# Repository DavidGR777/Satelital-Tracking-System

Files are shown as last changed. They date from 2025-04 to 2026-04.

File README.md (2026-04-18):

# Satelital-Tracking-System
Mecatronic system focused on the tracking of satelital network NOAA. 

This project presents the design and implementation of a low-cost, portable satellite tracking and signal processing system capable of receiving and generating images from NOAA satellites.

The main objective is to develop a system that improves the quality and frequency of satellite image acquisition by combining real-time tracking with signal conditioning and processing. The proposed solution addresses key limitations of traditional static reception systems, such as low signal quality and inefficiencies in manual tracking.

The system integrates multiple engineering domains, including:

- **Mechanical design**: Development of a portable structure and a tracking mechanism with at least two degrees of freedom (DoF) to orient a directional antenna toward the satellite.

- **Electronic design**: Implementation of signal acquisition using an RTL-SDR device, motor control hardware, and feedback sensors for closed-loop operation.

- **Software development**: Processing of orbital data, coordinate transformations, real-time control algorithms, and signal demodulation to generate satellite images.

The solution is specifically designed to operate within the NOAA satellite frequency range (137–138 MHz) and to function under real environmental conditions, ensuring robustness and portability.

This system has potential applications in environmental monitoring, disaster management, agriculture, telecommunications, and scientific research, providing accessible satellite data for governments, companies, and researchers.

<p align="center">
  
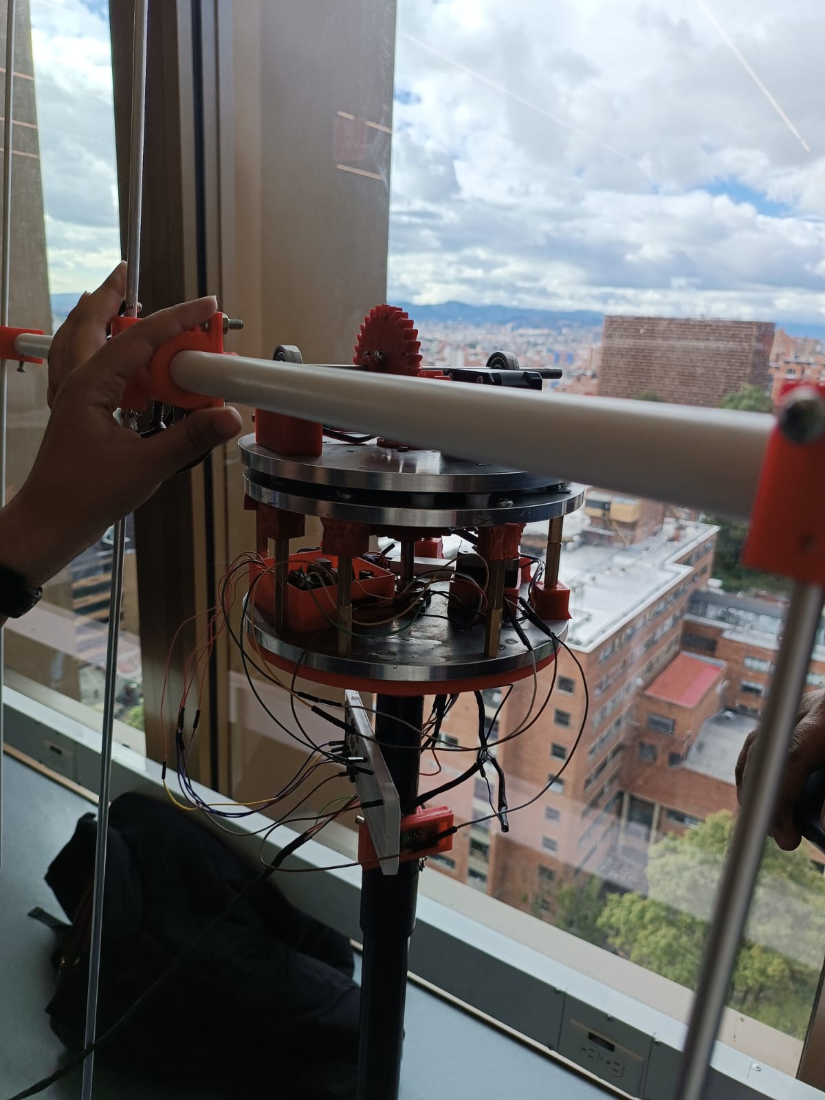
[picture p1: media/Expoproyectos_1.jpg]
  
</p>

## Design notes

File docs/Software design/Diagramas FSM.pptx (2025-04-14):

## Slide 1

RECEPTION_FSM

NULL/
/* recibe como parámetros:
bool Eusart_Rx_is_ready(), bool Eusar_READ() */
bool flag_inicio;
Static uint8_t* Rx_data = Rx_inicial;
uint16_t Azi, Azm, Azf;
uint8_t El, hi, hm, hf, mi, mm, mf;

No. | ESTADOS
0 | WAITING_SIGNAL
1 | RECEIVING_ALL_DATA
2 | ALL_PARAMETERS_SAVED

Eusart_Rx_is_ready() == 0
(Pregunta si hay otro dato para recibir)

1

Eusart_Rx_is_ready() == 1 /
*Rx_data = Eusar_READ();

0

flag_inicio == 1

*Rx_data != ‘$’ /
Rx_data++

flag_inicio == 0
(Pregunta si es momento de esperar recepción de datos)

2

*Rx_data == ‘$’/
(Deberán llegar 33 caracteres en ASCII decimal)
Azi = *(Rx_data-32)*100 *(Rx_data-31)*10 + *(Rx_data-30)
Azm = *(Rx_data-28)*100 *(Rx_data-27)*10 + *(Rx_data-26)
Azf = *(Rx_data-24)*100 *(Rx_data-23)*10 + *(Rx_data-22)
El = *(Rx_data-20)*10 + *(Rx_data-19)
hi = *(Rx_data-17)*10 + *(Rx_data-16)
mi = *(Rx_data-14)*10 + *(Rx_data-13)
hm = *(Rx_data-11)*10 + *(Rx_data-10)
mm = *(Rx_data-8)*10 + *(Rx_data-7)
hf = *(Rx_data-5)*10 + *(Rx_data-4)
mf = *(Rx_data-2)*10 + *(Rx_data-1)
flag_orientación = 1;
flag_inicio = 0;

Facultad de ingeniería – Pontificia Universidad Javeriana – Bogotá D.C

Eusart_Rx_is_ready()/Eusart_READ():
Estas funciones indican si el puerto de UART para recepción tiene un dato disponible para recibir. Además, permite guardarlo en una variable interna.

Breve descripción de la FSM:
Esta FSM hace lectura del pin Rx al que llegan los comando por el puerto serial, y sigue el estado del puerto por si ha llegado información. Una vez guardado el dato completo se mira qué tipo de comando fue ingresado y se modifica en dado caso el modo de operación del control, o la velocidad de referencia.

Fecha: 4 de mayo 2024

Autores: Valeria Jimenez, Jerónimo Rueda & David Esteban González

FSM: PWM_READER_FSM

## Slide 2

TRANSMISSION_FSM

flag_timer_Tx == 1 /
flag_timer_Tx = 0
step2dig(Az);
Tx_data = msj[0];

No. | ESTADOS
0 | WAITING_TIMER
1 | SENDING_AZ
2 | SENDING_EL

NULL/
/* recibe como parámetros:
bool flag_timer_Tx */
Static uint8_t* Tx_data;
Static uint8_t state = 0;
Static uint16_t Az;
Static uint8_t El;

Flag_Tx == 1 /
Tx_string();
(El ángulo se transmitirá en 3 dígitos. Ejm: Az: 15.3)

0

1

flag_timer_Tx == 0
(Pregunta si ya es momento de volver a enviar los ángulos al usuario)

Flag_Tx == 0

2

Flag_Tx == 0/
Flag_Tx == 1;
step2dig(El);
Tx_data = msj[0];

Flag_Tx == 1 /
Tx_string();
(El ángulo se transmitirá en 3 dígitos. Ejm: El: 15.3)

step2dig():
Esta función transforma los ángulos a transmitir en un arreglo de dígitos del mismo ángulo. De modo que en Tx se transmita posición por posición del arreglo
El arreglo a transmitir es de tipo char

Facultad de ingeniería – Pontificia Universidad Javeriana – Bogotá D.C

Tx():
Esta función controla el flujo de transmisión de cada digito de los ángulos hacia el puerto serial.Utiliza las funciones
Eusart_Tx_is_ready()/Eusart_WRITE():

Breve descripción de la FSM:
Esta FSM escribe en el pin Tx la posición angular Az y El de los motores. Espera que se produzaca la interrupción del timer, pregunta si se puede escribir en el puerto y una vez se completa el envío de Az, pasa a enviar El. Al finalizar, se queda esperando hasta que flag_timer_Tx sea nuevamente 1

Fecha: 4 de mayo 2024

Autores: Valeria Jimenez, Jerónimo Rueda & David Esteban González

FSM: TRANSMISSION_FSM

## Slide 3

INITIAL_POSITION_FSM

NULL/
/* recibe como parámetros:
bool flag_inicio, dir;
Static uint16_t Azi;
Static uint32_t N, steps;
if( Azi <= 180 ){
dir = 1;
}else{
dir = 0;
Azi -= 180;
}
num_steps(Azi); //determinar # pasos a dar

No. | ESTADOS
0 | WAITING_SIGNAL
1 | MOVING_ TO_AZi

flag_orientacion == 1/
control();
(se configura a la velocidad estándar de inicialización y dirección dir)

0

1

N <= steps/
(Pregunta si aún no se ha alcanzado el # de pasos esperado)

flag_orientacion == 0
(Pregunta si es hora de iniciar la orientación inicial)

N > steps /
N = 0;
flag_orientacion = 0;

Control():
Esta función establece y configuralas salidas de microcontrolador para el motor Az, para ir a la posición inicial Azi, según los parámetros recibidos.

num2steps():
Esta función calcula cuantos pasos se deben realizar para que el motor alcance el ángulo deseado

Breve descripción de la FSM:
Esta FSM describe el proceso de orientación inicial del sistema. Desde la orientación manual (Az = 0°) hasta el primer punto de trayectoria Azi

Fecha : 4 de mayo 2024

Facultad de ingeniería – Pontificia Universidad Javeriana – Bogotá D.C

Autores: Valeria Jimenez, Jerónimo Rueda & David Esteban González

FSM: INITIAL_POSITION_FSM

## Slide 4

OPERATION_FSM

NULL/
/* recibe como parámetros:
bool INICIO_GetValue();
bool operation_flag, flag_inicio;

No. | ESTADOS
0 | WAITING_BUTTON
1 | OPERATING_PHASE

INICIO_GetValue() == 1 && flag_inicio == 0/
control();
operation_flag = 1;

0

1

operation_flag == 1/
operation();
(Mantiene los motores en movimiento a velocidad cte según los parámetros ingresados. Cuando acaba la operación, operation_flag cambia a 0)

INICIO_GetValue() == 0 || flag_inicio == 1
(Pregunta si el botón de inicio fue activado y además si la recepción de datos ya fue ejecutada)

operation_flag == 0/
flag_inicio == 1;

Control():
Esta función establece y configura las salidas de microcontrolador para ambos motores, para ir a la velocidad calculada a través de los puntos de trayectoria del satélite

Breve descripción de la FSM:
Esta FSM describe la operación del sistema de modo que espera la señal de inicio (pulsador físico) y finaliza una vez se da la condición internamente en operation().

Fecha : 4 de mayo 2024

Facultad de ingeniería – Pontificia Universidad Javeriana – Bogotá D.C

Autores: Valeria Jimenez, Jerónimo Rueda & David Esteban González

FSM: OPERATION_FSM

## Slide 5

flag_inicio == 0/
(Espera a que la recepción de los parámetros finalice)
parametros();
flag_orientación = 1;
if( Azi <= 180 ) dir = 1;
else{
dir = 0;
Azi -= 180;
}
num_steps(Azi);

No. | ESTADOS
0 | WAITING_RECEPTION
1 | INITIAL_POSITION_PHASE
2 | WAITING_TRACKING_SIGNAL
3 | ENDING_INITIAL_POSITION
4 | TRACKING_PHASE

N <= steps/
(Pregunta si aún no se ha alcanzado
el # de pasos esperado)

MAIN_FSM

NULL/
/* recibe como parámetros:
uint_8_t state;

flag_orientacion == 1/
control()

0

1

INICIO_GetValue() == 0

operation_flag == 0/
flag_inicio == 1;

flag_orientacion == 0/

3

flag_inicio == 1/
recepción_fsm();

2

N > steps /
N = 0;
flag_orientacion = 0;

INICIO_GetValue() == 1/
control();
operation_flag = 1;

4

Breve descripción de la FSM:
Esta FSM describe el funcionamiento general del sistema de seguimiento. Partiendo desde la recepción, la ubicación inicial del sistema, y la operación de seguimiento. Una vez finaliza, espera por nuevas instrucciones de recepción

Fecha: : 4 de mayo 2024

operation_flag == 1/
operation();

Facultad de ingeniería – Pontificia Universidad Javeriana – Bogotá D.C

Autores: Valeria Jimenez, Jerónimo Rueda & David Esteban González

FSM: MAIN_FSM

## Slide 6

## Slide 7

Por puerto serial, el DC_ref se modifica directamente con el comando Wxxxxx. Queda guardado como valor entre 000.00 y 100.00% para el duti cycle

Aux = Lectura de ADC
DC_ref = Aux/4095*100 (Valor entre 0 y 100% para el duti cycle)

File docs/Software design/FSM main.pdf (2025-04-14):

No. | ESTADOS
0 | WAITING_RECEPTION

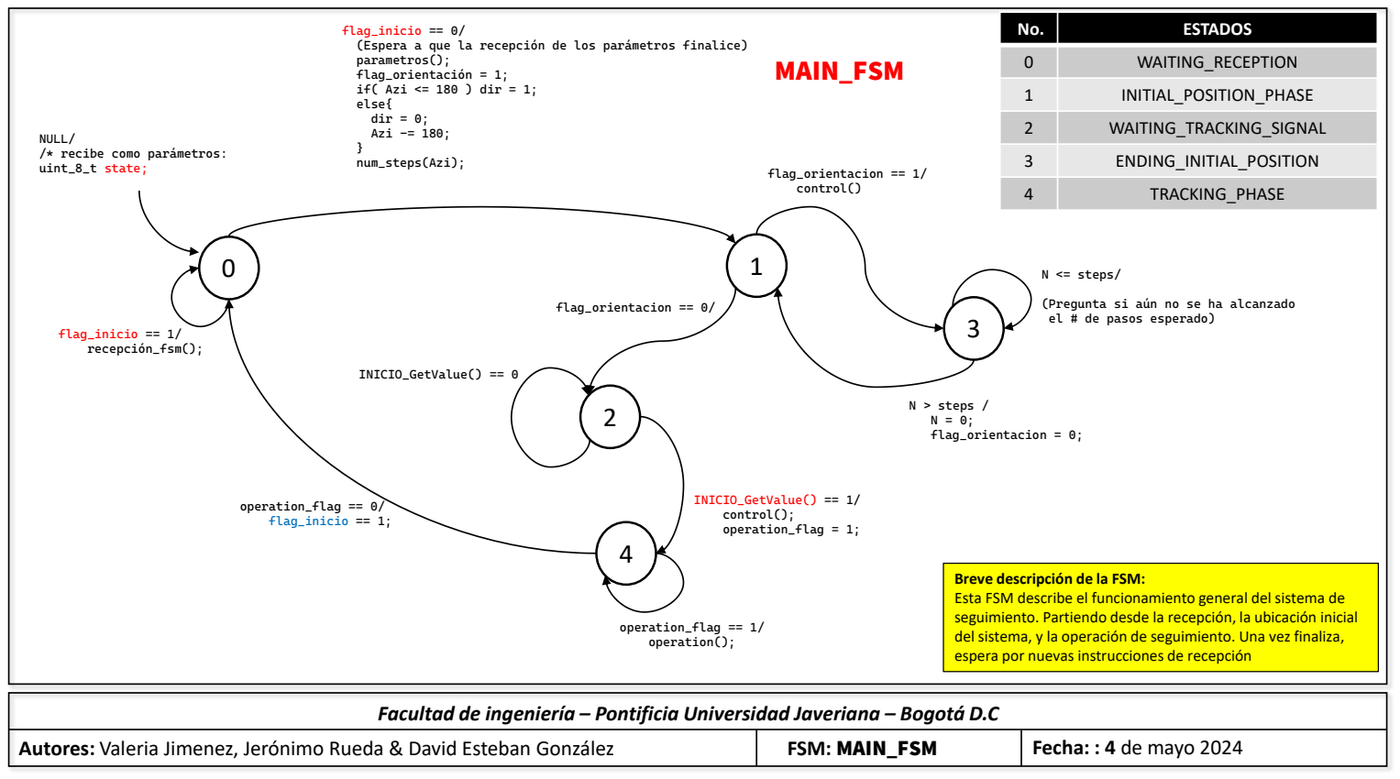
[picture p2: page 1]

1 | INITIAL_POSITION_PHASE
2 | WAITING_TRACKING_SIGNAL
3 | ENDING_INITIAL_POSITION
4 | TRACKING_PHASE

Breve descripción de la FSM:
Esta FSM describe el funcionamiento general del sistema de seguimiento. Partiendo desde la recepción, la ubicación inicial del sistema, y la operación de seguimiento. Una vez finaliza, espera por nuevas instrucciones de recepción
Autores: Valeria Jimenez, Jerónimo Rueda & David Esteban González | FSM: MAIN_FSM

## Facultad de ingeniería – Pontificia Universidad Javeriana – Bogotá D.C Fecha: : 4 de mayo 2024

# MAIN_FSM

0 | 1

flag_inicio == 0/
(Espera a que la recepción de los parámetros finalice) parametros();
flag_orientación = 1;
if( Azi <= 180 ) dir = 1;
else{
dir = 0;
Azi -= 180;
}
num_steps(Azi);

NULL/
/* recibe como parámetros: uint_8_t state;

2

4

flag_inicio == 1/ | 3
recepción_fsm();

flag_orientacion == 1/
control()

flag_orientacion == 0/

N <= steps/

(Pregunta si aún no se ha alcanzado el # de pasos esperado)

N > steps /
N = 0;
flag_orientacion = 0;

INICIO_GetValue() == 1/
control();
operation_flag = 1;

INICIO_GetValue() == 0

operation_flag == 1/
operation();

operation_flag == 0/
flag_inicio == 1;

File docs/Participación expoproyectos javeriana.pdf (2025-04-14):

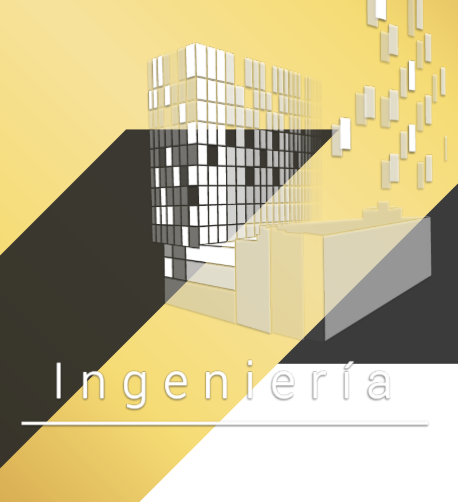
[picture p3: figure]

# Certificado de Participación

EN RECONOCIMIENTO AL PROYECTO Sistema de seguimiento satelital

Valeria Jiménez Moyano, David González Rozo, Jerónimo Rueda Giraldo

POR SU COMPROMISO Y PARTICIPACIÓN EXPO PROYECTOS 2410
PONTIFICIA UNIVERSIDAD JAVERIANA

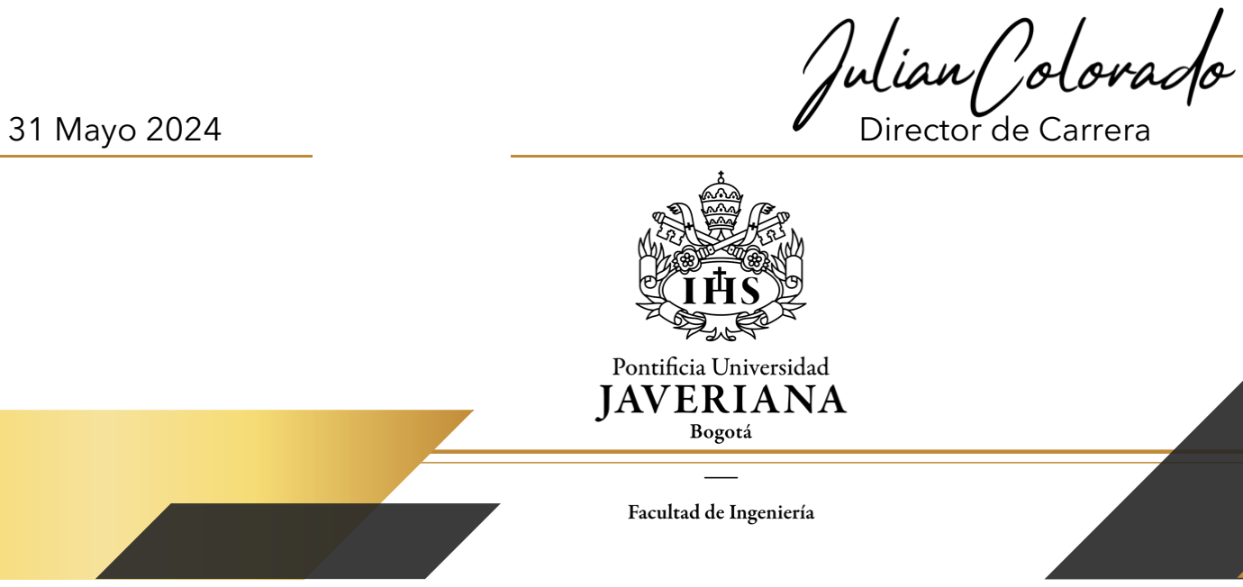
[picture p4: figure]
31 Mayo 2024; Director de Carrera

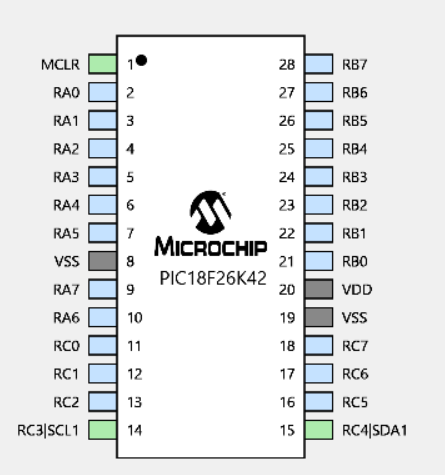
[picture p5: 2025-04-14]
docs/Electronic design/PIC18F26K42.png

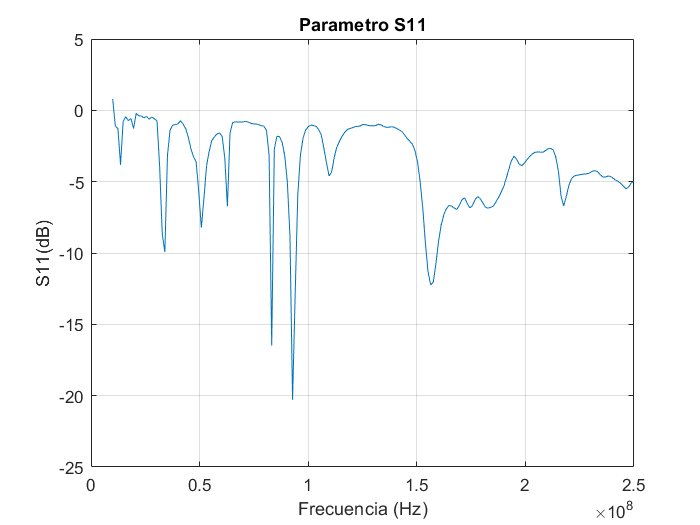
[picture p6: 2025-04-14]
docs/Sintonizacion antena.png

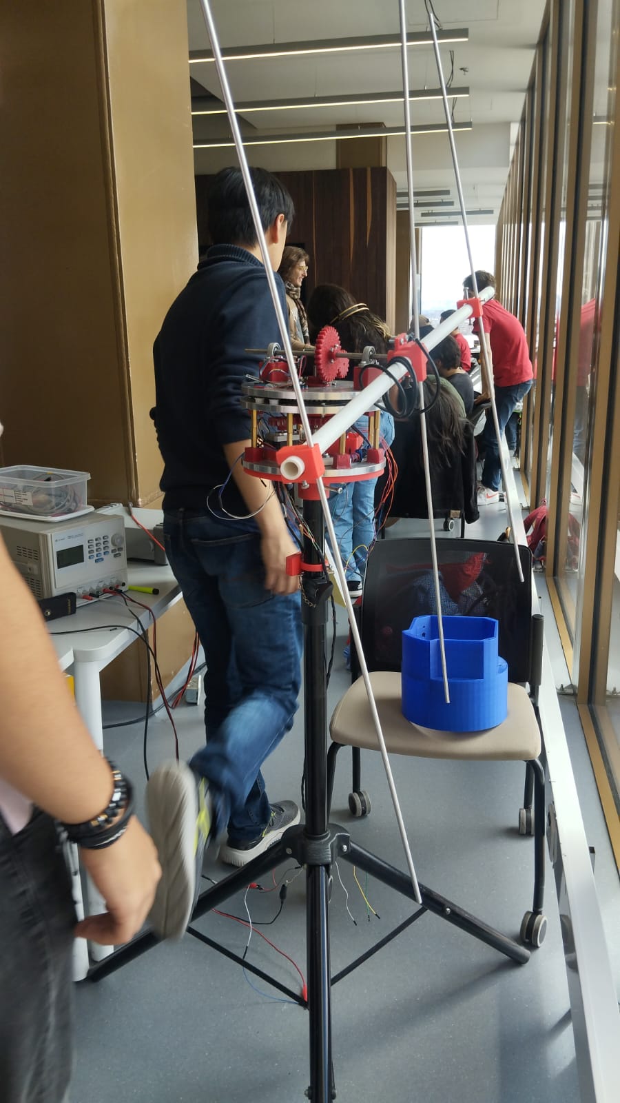
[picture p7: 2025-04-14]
media/Expoproyectos 2.jpg

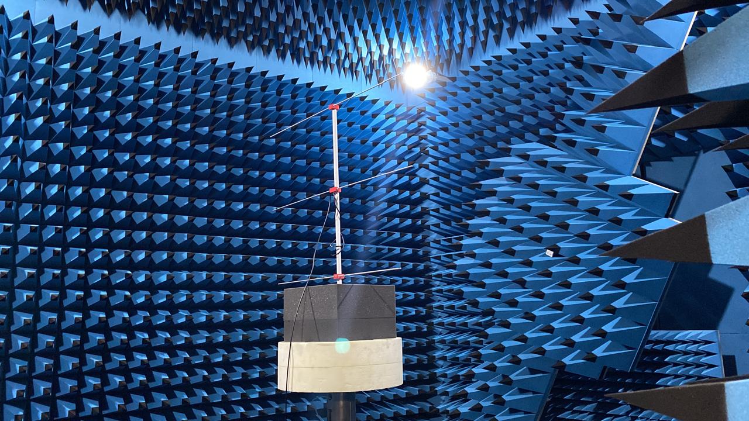
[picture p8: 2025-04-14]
media/Sintonización.jpeg

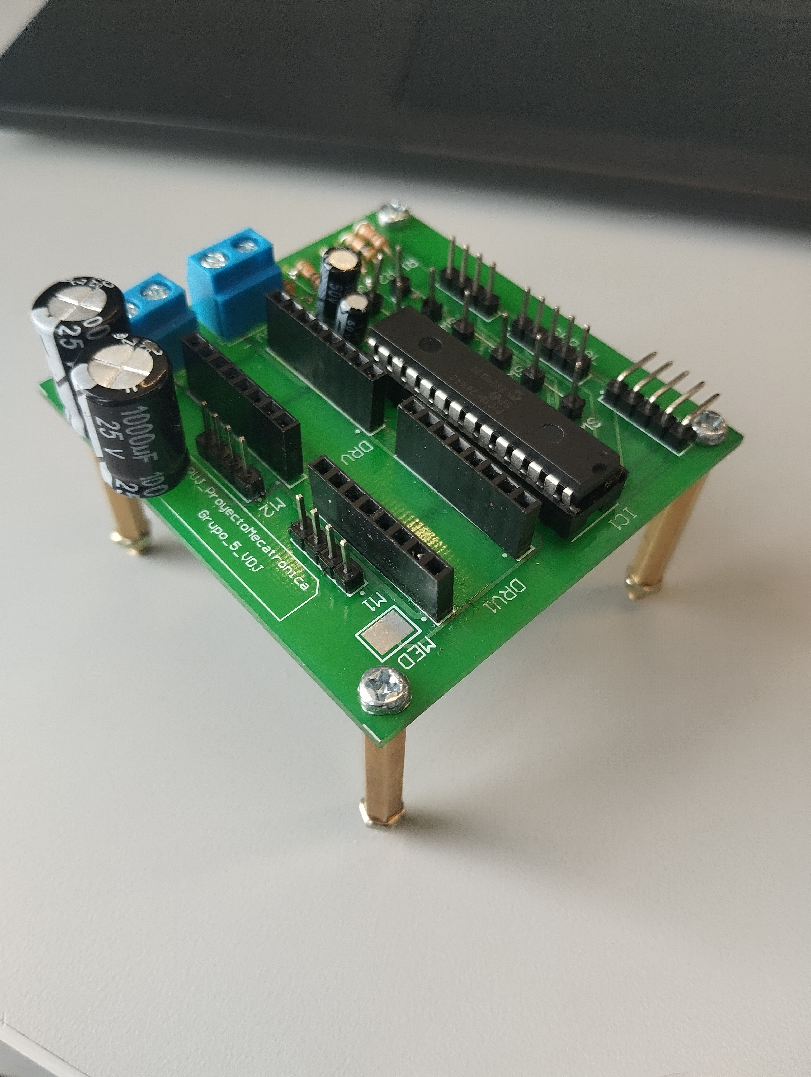
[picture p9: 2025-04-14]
media/PCB.jpg

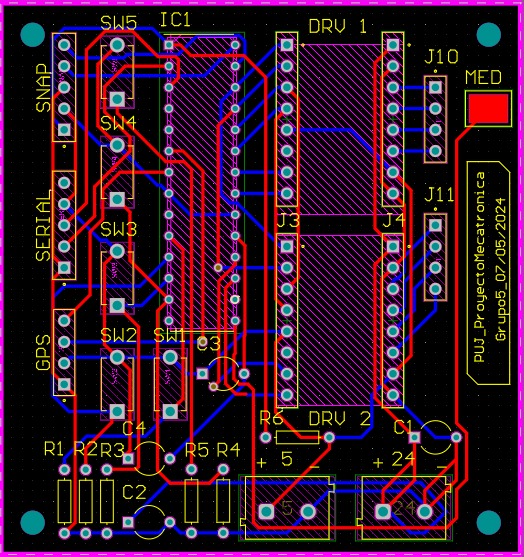
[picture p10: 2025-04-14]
src/PCB/PCB2D.jpeg

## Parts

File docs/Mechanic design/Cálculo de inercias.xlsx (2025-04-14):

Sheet: Hoja1
 | Parte superior PARA MOTOR INFERIOR
 | Antena | engranaje1 sup | engranaje2 sup | eje sup | motor superior | Soporte L | electrónica | brida motor | brida engranaje | brida antena | contrapeso | chumasera1 | escalon1 | chumasera2 | escalon2 | chumasera3 | escalon3
Material |  | No sé | No sé | aluminio |  | No sé |  | aluminio | aluminio | bronce | bronce |  | PETG |  | PETG |  | PETG | Masa total (downward para rodmientos )
masa (kg) | 1.28565 | 0.34172 | 0.08331 | 0.1 | 0.54871 | 0.03626 | 0.17 | 0.04355 | 0.06 | 0.15402 | 0.371 | 0.05013 | 0.05528 | 0.05013 | 0.05528 | 0.05013 | 0.05528 | 3.51045 |  |  | Parte superior PARA MOTOR SUPERIOR
rext (m) |  | 0.04 | 0.02125 |  |  |  |  |  |  |  | 0.02 |  |  |  |  |  |  |  |  |  |  | Antena | engranaje1 sup | engranaje2 sup | eje sup | brida motor | brida engranaje | brida antena | motor (datashet)
rint o L |  | 0.008 | 0.01 | 0.008 |  | rext1 |  | 0.0075 | 0.01 |  |  |  |  |  |  |  |  | MENOS: eje sup (para desplazamiento a eje del motor inferior) |  |  | Material |  | No sé | No sé | aluminio | aluminio | aluminio | aluminio |  | masa TOTAL | MAS: disco (para peso sobre rodamientos de transferencia
a |  |  |  |  | 0.0405 | rext2 |  | 0.02 | 0.025 | 0.018 |  | 0.02276 | 0.02276 | 0.02276 | 0.02276 | 0.02276 | 0.02276 |  |  |  | masa (kg) |  |  |  |  |  |  |  |  | 0
b |  |  |  |  | 0.042 | rint |  | 0.005 | 0.008 | 0.06221 |  | 0.05485 | 0.05485 | 0.05485 | 0.05485 | 0.05485 | 0.05485 |  |  |  | radio (mm) |  |  |  |  |  |  |  |  | MENOS: brida y eng1 (para desplazar todo al eje del motor
unidades | 1 | 1 | 1 | 1 | 1 | 1 | 1 | 1 | 1 | 1 | 1 | 1 | 1 | 1 | 1 | 1 | 1 |  |  |  | rext1
d (distancia al eje) m | 0.192 | 0.0245 | 0.05811 | 0.04693 | 0.05485 | 0.0533 | 0.0703 | 0.0549 | 0.014 | 0.169 | 0.084 | 0.0482 | 0.0482 | 0.06104 | 0.06104 | 0.0838 | 0.0838 |  |  |  | rext2
Inercia (kg m2) |  | 0.00014215552 | 1.148766797e-05 | 5.333333333e-07 | 0.0001556621681 | 2.410829e-05 | 0.0001203339 | 5.511796875e-06 | 1.2795e-05 | 5.383106942e-05 | 0.0255324055 | 1.473212127e-05 | 1.624559473e-05 | 1.473212127e-05 | 1.624559473e-05 | 1.473212127e-05 | 1.624559473e-05 |  |  |  | rint
Inercia despl. | 0.0473942016 | 0.00034727295 | 0.0002928065516 | 0.0002207758233 | 0.001806468549 | 0.0001271189614 | 0.0009604892 | 0.0001367719324 | 2.4555e-05 | 0.004452796289 | 0.0281501815 | 0.0001311961425 | 0.0001446743019 | 0.0002015105659 | 0.0002222123296 | 0.0003667670385 | 0.0004044460779 | Inercia TOTAL |  |  | d (distancia al eje) mm |  | 0 |  |  | 0 |  |  | 0
Inercia TOTAL | 0.0473942016 | 0.00034727295 | 0.0002928065516 | 0.0002207758233 | 0.001806468549 | 0.0001271189614 | 0.0009604892 | 0.0001367719324 | 2.4555e-05 | 0.004452796289 | 0.0281501815 | 0.0001311961425 | 0.0001446743019 | 0.0002015105659 | 0.0002222123296 | 0.0003667670385 | 0.0004044460779 | 0.08538424481 |  |  | Inercia (kg mm2) |  | 0 | 0 | 0 | 0 | 0 | 0 |  | Inercia TOTAL
 |  |  |  |  |  |  |  |  |  |  |  |  |  |  |  |  |  |  |  |  | Inercia despl. | 0 | 0 | 0 | 0 | 0 | 0 | 0 | 0 | 0
 |  |  |  |  |  |  |  |  |  | 5.941619142e-05
 |  |  |  |  |  |  |  |  |  |  |  |  |  |  |  |  |  |  |  |  |  |  |  | BRIDAS engranaje y antena TIENEN rint = 8 mm
 |  |  |  |  |  |  |  |  |  |  |  |  |  |  |  |  |  |  |  |  |  |  |  | BRIDA e motor TIENEN rint = …..............
 | Parte inferior PARA MOTOR INFERIOR
 |  | disco | eje inf | brida de giro | brida engranaje | brida motor | engranaje1 inf | engranaje2 inf | motor (datasheet)
 | Material | aluminio | aluminio | aluminio | aluminio | aluminio | No sé | No sé |  | Masa total (para carga axial rodamientos, es decir la vertical)
 | masa (kg) | 1.65 | 0.07402 | 0.05976 | 0 | 0.04355 |  |  |  | 1.82733
 | radio (m) |  | 0.004 |  | 0 |  |  |  |  | MENOS: brida motor y eng1 (tanto para el peso como para el desplazamos a eje del motor
 | rext1 | 0.03 |  | 0.01 | 0 |  |  |  |  | 1.82733 |  |  |  | Antena PARA MOTOR INFERIOR |  |  |  |  |  |  | Antena PARA MOTOR SUPERIOR
 | rext2 | 0.11 |  | 0.025 | 0 |  |  |  |  |  |  |  |  |  | Boom | dipolo | reflector | director | contrapeso |  |  | Boom | dipolo | reflector | director | contrapeso
 | rint | 0.008 |  | 0.008 | 0 | 0.005 |  |  |  |  |  |  |  | Material | PVC | Aluminio | Aluminio | Aluminio | bronce | masa TOTAL | Material | PVC | Aluminio | Aluminio | Aluminio | bronce | masa TOTAL
 | d (distancia al eje) mm | 0 | 0 | 0 | 0 | 0 | 0 |  | 0 |  |  |  |  | masa (kg) | 0.715 | 0.04677 | 0.09486 | 0.08636 | 0.296 | 1.23888 | masa (kg) | 0.715 | 0.04677 | 0.09486 | 0.08636 | 0.296 | 1.28565
 | Inercia (kg m2) | 0.0108306 | 4.7808e-07 | 2.548764e-05 | 0 | 1.08875e-06 | 0 | 0 | 8.2e-06 | Inercia TOTAL |  |  |  | Longitud (m) | 1.5 | 0.545 | 1.070 | 1.010 |  | MAS: 1 dipolo | Longitud (m) | 1.5 | 0.545 | 1.070 | 1.010 |  | MAS: 1 dipolo
 | Inercia despl. | 0.0108306 | 4.7808e-07 | 2.548764e-05 | 0 | 1.08875e-06 | 0 | 0 | 8.2e-06 | 0.01086585447 |  |  |  | rext (m) | 0.0167 |  |  | r | 0.04000 |  | rext (m) | 0.0167 |  |  | r | 0.04000
 |  |  |  |  |  |  |  |  |  |  |  |  |  | rint (m) | 0.0127 |  |  | h | 0.0458 |  | rint (m) | 0.0127 |  |  | h | 0.0458
 |  |  |  |  |  |  |  |  |  |  |  |  |  | d (distancia al eje) m | 0.31145 | 0.60809 | 0.23687 | 1.03382 | 0.5293 |  | d (distancia aleje) m | 0.246 | 0.558 | 0.12 | 0.996 | 0.504
 |  |  |  |  |  |  |  |  | mk |  |  |  |  | Inercia (kg m2) | 0.1341205451 | 0.00463061975 | 0.0090504345 | 0.007341319667 | 0.0001701417867 |  | Inercia (kg m2) | 0.1341205451 | 0.008550359667 | 0.0090504345 | 0.007341319667 | 0.0001701417867
 |  |  |  |  |  |  |  |  |  |  |  |  |  | Inercia despl. | 0.2034656632 | 0.02192492392 | 0.01437278217 | 0.09964148798 | 0.08309705483 | TOTAL | Inercia despl. | 0.1773828283 | 0.02311285395 | 0.0104164185 | 0.09301182143 | 0.07535887779 | Inercia TOTAL | Torque
 |  |  |  |  |  |  |  |  |  |  |  |  |  | Inercia TOTAL | 0.2034656632 | 0.04384984784 | 0.01437278217 | 0.09964148798 | 0.08309705483 | 0.444426836 | Inercia TOTAL | 0.1773828283 | 0.04622570789 | 0.0104164185 | 0.09301182143 | 0.07535887779 | 0.4023956539 | 0.06320816151
 |  |  |  |  |  |  |  |  |  | VELOCIDADES MÁXIMAS ( manual)
 |  |  |  |  |  |  |  |  |  | w_Az (rad/s) | 0.10472
 |  |  |  |  |  |  |  |  |  | w_El (rad/s) | 0.15708 |  |  |  |  |  |  |  |  |  |  |  |  |  |  |  | 0.03682087962
 |  |  |  |  |  |  |  |  |  |  | pi rad en 30 s
 |  |  |  |  |  |  |  |  |  |  |  |  |  |  |  |  |  |  |  |  |  |  | I contrapeso = (1/4)*m*r^2
 |  |  |  |  |  |  |  |  |  |  |  |  |  | Antena PARA MOTOR INFERIOR
 |  |  |  |  |  |  |  |  |  |  |  |  |  |  | Boom | dipolo | reflector | director | contrapeso
 |  |  |  |  |  |  |  |  |  |  |  |  |  | Material | PVC | Aluminio | Aluminio | Aluminio | bronce
 |  |  |  |  |  |  |  |  |  |  |  |  |  | masa (kg) | 0.715 | 0.04677 | 0.09486 | 0.08636 | 0.296
 |  |  |  |  |  |  |  |  |  |  |  |  |  | Longitud (mm) | 1.5 | 0.545 | 1.070 | 1.010
 |  |  |  |  |  |  |  |  |  |  |  |  |  | rext (mm) | 0.0167 |  |  | a
 |  |  |  |  |  |  |  |  |  |  |  |  |  | rint (mm) | 0.0127 |  |  | b
 |  |  |  |  |  |  |  |  |  |  |  |  |  | d (distancia al eje) mm
 |  |  |  |  |  |  |  |  |  |  |  |  |  | Inercia (kg mm2) | 0.0001573401401 | 0.00463061975 | 0.0090504345 | 0.007341319667 | 0
 |  |  |  |  |  |  |  |  |  |  |  |  |  | Inercia despl. | 0.0001573401401 | 0.00463061975 | 0.0090504345 | 0.007341319667 | 0
 |  |  |  |  |  |  |  |  |  |  |  |  |  | Inercia TOTAL | 0.0001573401401 | 0.0092612395 | 0.0090504345 | 0.007341319667 | 0

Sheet: Hoja2
 |  |  |  |  |  |  |  |  |  |  |  | TABLA DE INERCIAS MOTOR ELEVATION
TABLA DE INERCIAS MOTOR AZIMUTH
 |  |  |  |  |  |  |  |  |  |  |  |  | Material | masa (kg) | Longitud (m) | rint (m) | rext1 (m) | rext2 (m) | Inercia (kg m2) | d (distancia al eje) m | Inercia despl.
 | Material | masa (kg) | Longitud (m) | rint (m) | rext1 (m) | rext2 (m) | a (m) | b (m) | Inercia (kg m2) | d (distancia al eje) m | Inercia despl. | Antena
Antena |  |  |  |  |  |  |  |  |  |  |  | Boom | PVC | 0.7149 | 1.5000 | 0.0127 | 0.0167 |  | 0.1341 | 0.2460 | 0.1774
Boom | PVC | 0.7149 | 1.5000 | 0.0127 | 0.0167 |  |  |  | 0.1341 | 0.3115 | 0.2035 | dipolos | aluminio | 0.1072 | 0.5450 |  |  |  | 0.0027 | 0.6364 | 0.0461
dipolos | aluminio | 0.1072 |  |  | 0.0063 |  |  |  | 2.161286e-06 | 0.6081 | 0.0219 | reflector | aluminio | 0.1020 | 1.0700 |  |  |  | 0.0097 | 0.1300 | 0.0115
reflector | aluminio | 0.1020 |  |  | 0.0063 |  |  |  | 0.0091 | 0.2369 | 0.0144 | director | aluminio | 0.0955 | 1.0100 |  |  |  | 0.0081 | 1.0073 | 0.1050
director | aluminio | 0.0955 |  |  | 0.0063 |  |  |  | 0.0073 | 1.0338 | 0.0996 | contrapeso | bronce | 0.3080 | 0.0458 |  | 0.0400 |  | 0.0002 | 0.5040 | 0.0784
contrapeso | bronce | 0.3080 | 0.0458 |  | 0.0400 |  |  |  | 0.0002 | 0.5293 | 0.0831 | soporte dipolo | PE alto impacto | 0.02447 |  |  |  |  | 8.07545e-06 | 0.568 | 0.0079
soporte dipolo | PE alto impacto | 0.02447 |  |  |  |  |  |  | 6.54169e-06 | 0.568 | 0.0079 | soporte reflector | PE alto impacto | 0.01929 |  |  |  |  | 4.70458e-06 | 0.13 | 0.0003
soporte reflector | PE alto impacto | 0.01929 |  |  |  |  |  |  | 5.94917e-06 | 0.13 | 0.0003 | soporte director | PE alto impacto | 0.01929 |  |  |  |  | 4.70458e-06 | 1.0073 | 0.0196
soporte director | PE alto impacto | 0.01929 |  |  |  |  |  |  | 5.94917e-06 | 1.0073 | 0.0196 | TOTAL |  | 1.39064 |  |  |  |  |  |  | 0.44615
TOTAL |  | 1.39064 |  |  |  |  |  |  |  |  | 0.45031
 |  |  |  |  |  |  |  |  |  |  |  | Parte superior
Parte superior |  |  |  |  |  |  |  |  |  |  |  | eje sup | acero | 0.1000 |  |  | 0.0080 |  | 3.2e-06 | 0.0000 | 3.2e-06
engranaje1 El | acero AISI 1020 | 0.3417 | 0.0100 | 0.0080 | 0.0400 |  |  |  | 0.0001 | 0.0245 | 0.0004 | brida antena | bronce | 0.1540 |  |  |  |  | 0.00006 | 0.0000 | 0.0001
engranaje2 El | acero AISI 1020 | 0.0833 | 0.0100 | 0.0100 | 0.0213 |  |  |  | 1.218191797e-05 | 0.0581 | 0.0003 | acople antena | PETG | 0.02264 |  |  |  |  | 0.00002 | 0.0000 | 2.311239e-05
eje horizontal | acero | 0.1000 | 0.0080 |  |  |  |  |  | 5.333333333e-07 | 0.0469 | 0.0002 | Inercia motor | . |  |  |  |  |  | 8.2e-06 | 0.0000 | 8.2e-06
motor superior | . | 0.5487 |  |  |  |  |  |  | 0.0005 | 0.0549 | 0.0021 | TOTAL |  | 0.2767 |  |  |  |  |  |  | 0.0001
Soporte L | acero | 0.0363 |  |  |  |  |  |  | 0.00006 | 0.0533 | 0.0002
electrónica | PE alto impacto | 0.1700 |  |  |  |  |  |  | 0.00006 | 0.0703 | 0.0009 | Transmisión
brida motor | bronce | 0.0435 | 0.0200 | 0.0050 | 0.0075 | 0.0200 |  |  | 6.963463542e-06 | 0.0549 | 0.0001 | brida motor | bronce | 0.0347 |  | 0.0050 | 0.0075 | 0.0200 | 8.7935625e-06 | 0.0000 | 8.7935625e-06
brida engranaje | bronce | 0.0600 | 0.0200 | 0.0080 | 0.0100 | 0.0250 |  |  | 1.4795e-05 | 0.0140 | 2.6555e-05 | brida engranaje | bronce | 0.0598 |  | 0.0080 | 0.0100 | 0.0250 | 2.548764e-05 | 0.0000 | 2.548764e-05
brida antena | bronce | 0.1540 |  |  |  |  |  |  | 0.00199 | 0.1690 | 0.0064 | engranaje1 sup | acero AISI 1020 | 0.0833 |  |  |  |  | 6.7689375e-05 | 0.0000 | 0.0001
acople antena | PETG | 0.02264 |  |  |  |  |  |  | 6.53528e-06 | 0.1700 | 0.0007 | engranaje2 sup | acero AISI 1020 | 0.3417 |  |  |  |  | 0.0002 | 0.0000 | 0.0002
contrapeso | bronce | 0.3710 |  |  | 0.0200 |  |  |  | 0.0255 | 0.0840 | 0.0282 | TOTAL |  | 0.5195 |  |  |  |  |  |  | 0.0003
chumasera1 | . | 0.0501 |  |  |  |  |  |  | 0.0008 | 0.0482 | 0.0009
escalon1 | PETG | 0.0553 |  |  |  |  | 0.0228 | 0.0549 | 1.624559473e-05 | 0.0482 | 0.0001 | TOTALES | MASA | 2.18683 |  |  |  |  |  | INERCIA | 0.44659
chumasera2 | . | 0.0501 |  |  |  |  |  |  | 0.0008 | 0.0610 | 0.0010
escalon2 | PETG | 0.0553 |  |  |  |  | 0.0228 | 0.0549 | 1.624559473e-05 | 0.0610 | 0.0002
chumasera3 | . | 0.0501 |  |  |  |  |  |  | 0.0008 | 0.0838 | 0.0012
escalon3 | PETG | 0.0553 |  |  |  |  | 0.0228 | 0.0549 | 1.624559473e-05 | 0.0838 | 0.0004
base giratoria | aluminio | 1.65 | 0.03 | 0.0080 | 0.0600 | 0.1100 |  |  | 0.0067 | 0.0000 | 0.0067
eje vertical | acero | 0.07402 |  |  | 0.0040 |  |  |  | 5.9216e-07 | 0.0000 | 5.9216e-07
Inercia motor | . |  |  |  |  |  |  |  | 8.2e-06 |  | 8.2e-06
Cubierta | PE alto impacto | 0.8556 |  |  |  |  |  |  | 0.0108 | 0.0000 | 0.0108
Tapa de cubierta | PE alto impacto | 0.17662 |  |  |  |  |  |  | 0.0011 | 0.0000 | 0.0011 |  |  |  | 0.00004
TOTAL |  | 5.00368 |  |  |  |  |  |  |  |  | 0.06175 |  |  |  | 0.00002
 |  |  |  |  |  |  |  |  |  |  |  |  |  |  | 0.00006
Transmisión
brida engranaje | bronce | 0.05976 |  | 0.0100 | 0.0250 | 0.0080 |  |  | 2.548764e-05 | 0.0000 | 2.548764e-05
brida motor | bronce | 0.04355 |  | 0.0050 | 0.0075 | 0.0200 |  |  | 1.08875e-06 |  | 1.08875e-06
engranaje1 Az | acero AISI 1020 |  |  |  |  |  |  |  | 0.0000 |  | 0.0000
engranaje2 Az | acero AISI 1020 |  |  |  |  |  |  |  | 0.0000 | 0.0000 | 0.0000
TOTAL |  | 0.10331 |  |  |  |  |  |  |  |  | 0.00003
TOTALES | MASA | 5.37717 |  |  |  |  |  |  |  | INERCIA | 0.49917
 |  |  |  | 730.13
 |  |  |  | 7315.35
 |  |  |  | 8045.48

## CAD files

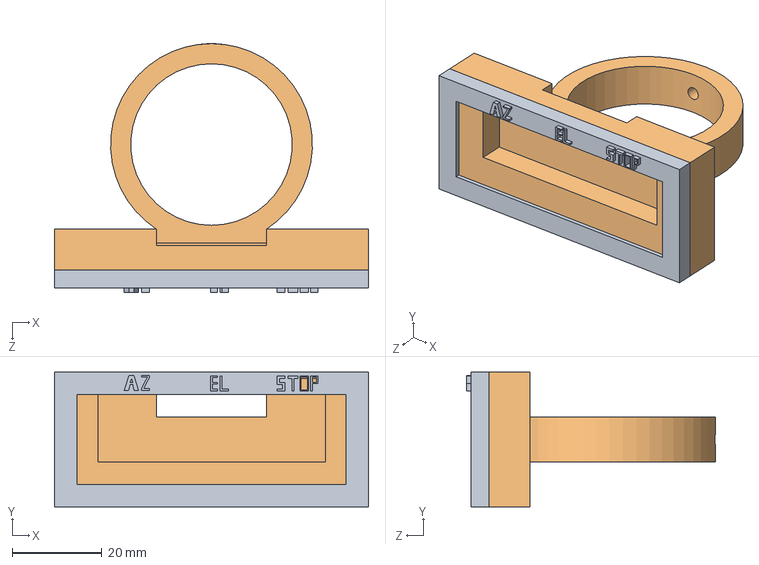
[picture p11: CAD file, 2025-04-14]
src/cad-design/Botones/BOTONES.SLDASM
70.0 x 30.0 x 55.5 mm
soporte botones
Cartel

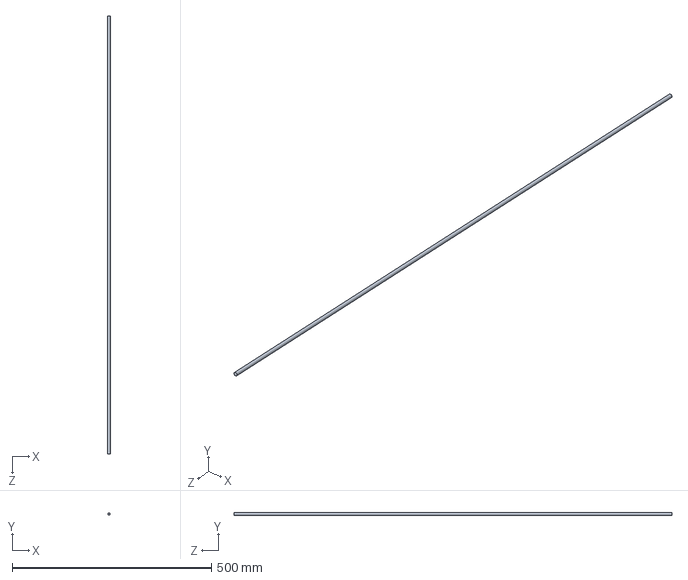
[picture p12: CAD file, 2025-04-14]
src/cad-design/Antena/Reflector-1.SLDPRT
6.35 x 6.35 x 1100.0 mm

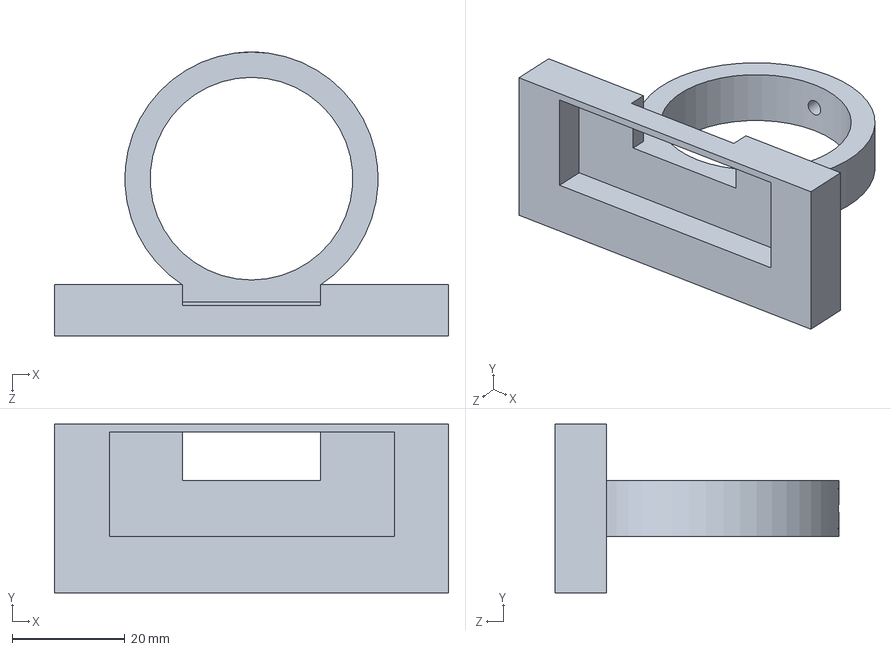
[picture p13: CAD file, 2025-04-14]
src/cad-design/Botones/soporte botones.SLDPRT
70.0 x 30.0 x 50.5 mm

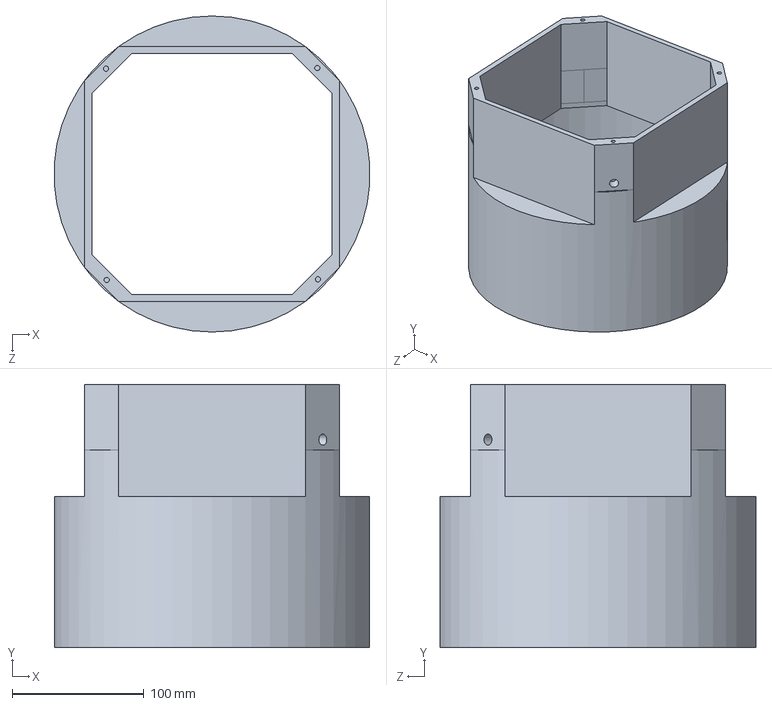
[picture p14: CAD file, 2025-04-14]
src/cad-design/caja estructura/Cubierta estructura.SLDPRT
239.5 x 200.0 x 240.0 mm

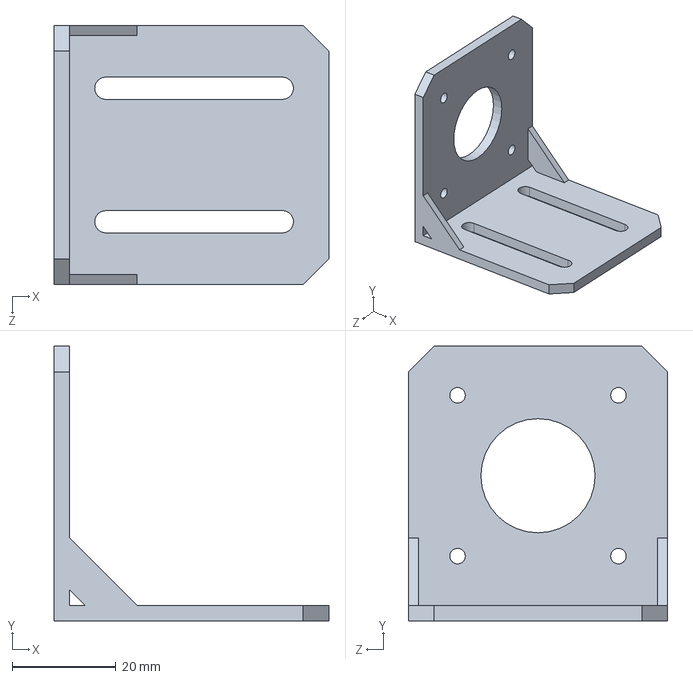
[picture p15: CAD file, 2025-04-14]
src/cad-design/Macro/Soporte L motor.SLDPRT
53.0 x 53.0 x 50.0 mm

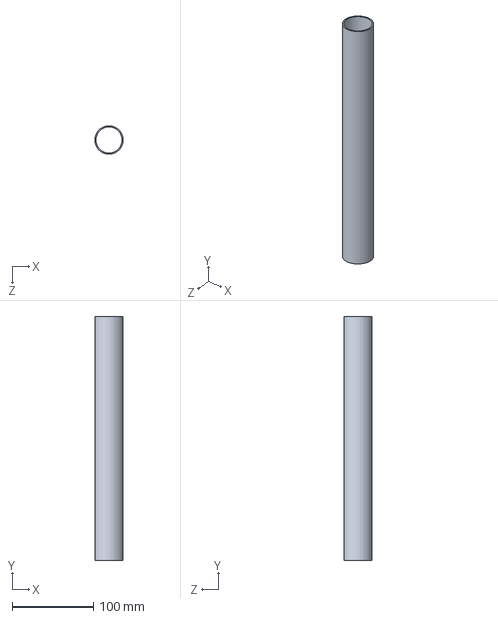
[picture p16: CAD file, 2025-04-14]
src/cad-design/Tripode/extra tripode.SLDPRT
35.0 x 300.0 x 35.0 mm

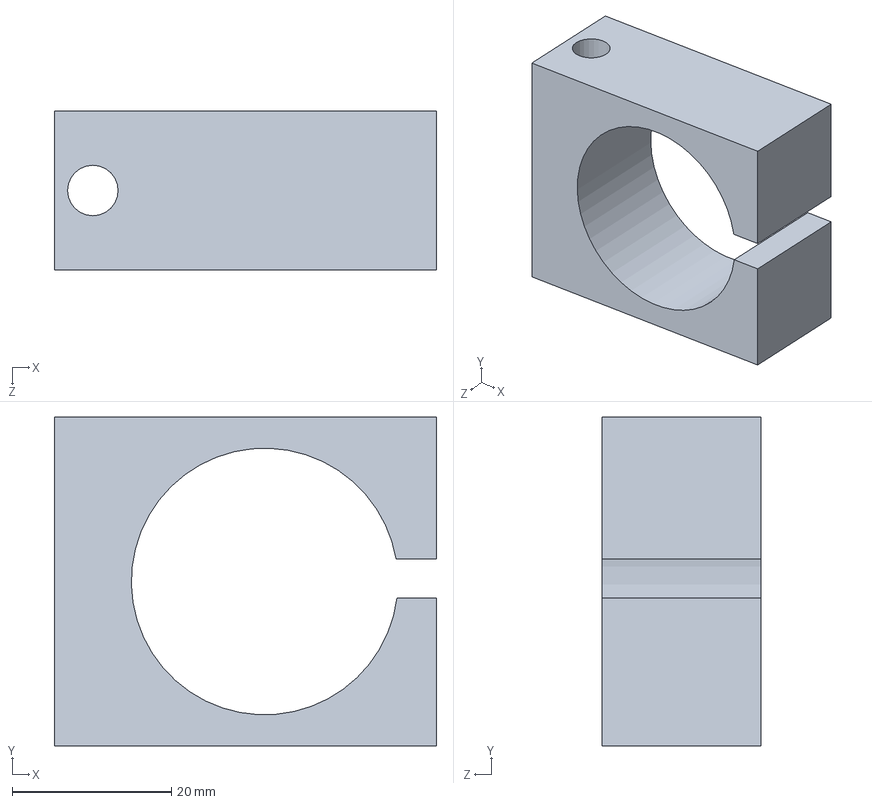
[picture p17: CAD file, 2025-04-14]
src/cad-design/Antena/Abrazadera_Barras.SLDPRT
48.0 x 41.3 x 20.0 mm

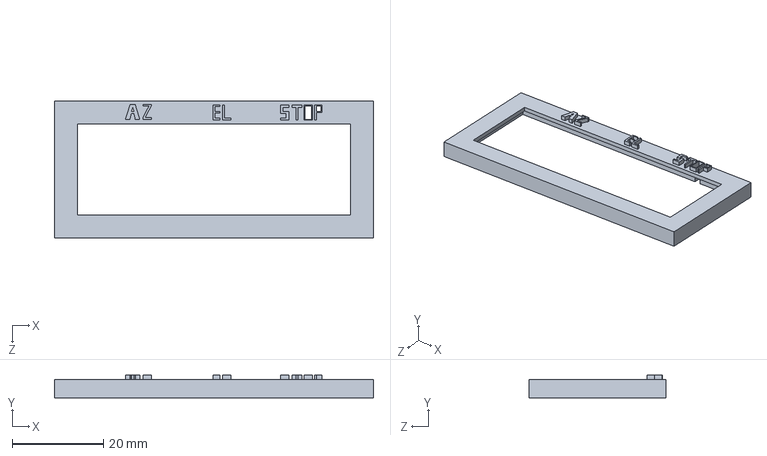
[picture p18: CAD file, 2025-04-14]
src/cad-design/Botones/Cartel.SLDPRT
70.0 x 5.00 x 30.0 mm

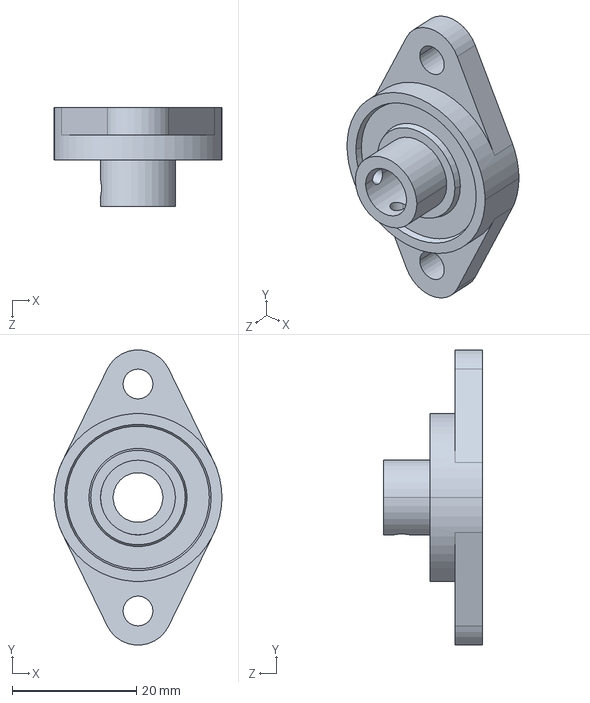
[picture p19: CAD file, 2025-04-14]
src/cad-design/caja estructura/kfl08.step.SLDPRT
27.0 x 47.4 x 16.0 mm

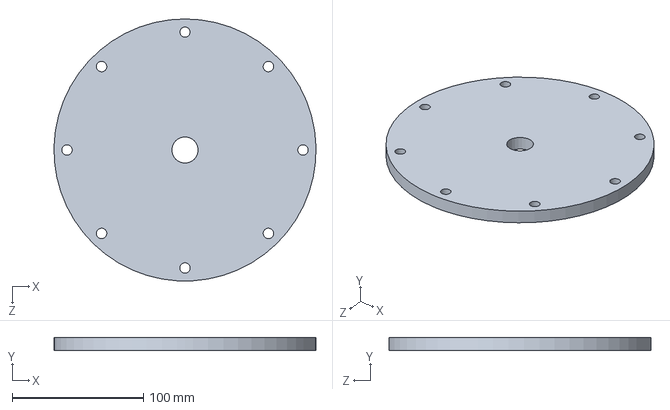
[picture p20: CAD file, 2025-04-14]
src/cad-design/Macro/base botton.SLDPRT
199.9 x 10.0 x 200.0 mm

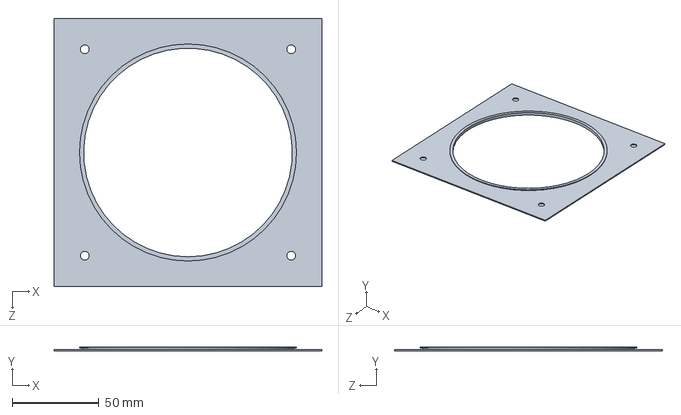
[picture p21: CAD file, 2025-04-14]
src/cad-design/rodamiento de mesa/placa1.SLDPRT
154.2 x 2.30 x 154.2 mm

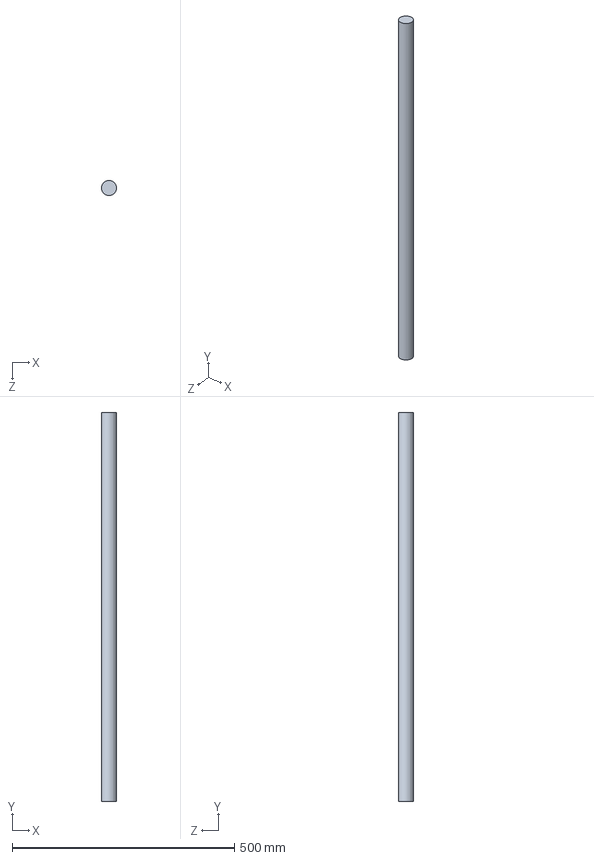
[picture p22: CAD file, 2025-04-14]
src/cad-design/Antena/BoomAntena.SLDPRT
34.0 x 875.9 x 34.0 mm

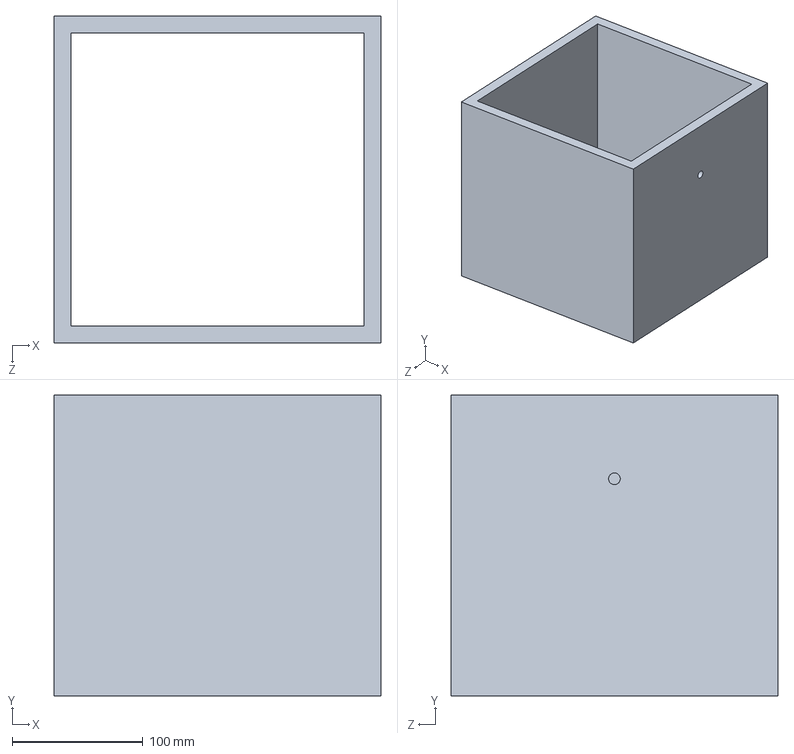
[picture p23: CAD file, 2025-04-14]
src/cad-design/caja estructura/tapa cubierta.SLDPRT
250.0 x 230.0 x 250.0 mm

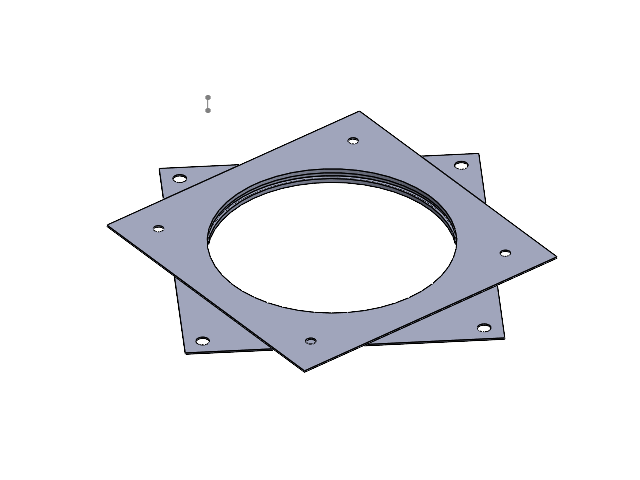
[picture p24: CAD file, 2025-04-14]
src/cad-design/rodamiento de mesa/rodamiento de mesa.SLDASM
soporte
placa1
placa2

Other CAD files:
src/cad-design/Antena/AntenaEnsamble.SLDASM
src/cad-design/Macro/chumasera top.SLDASM
src/cad-design/Macro/Acople_Tripode.SLDASM
src/cad-design/Macro/rodamiento 8 mm.SLDPRT
src/cad-design/Antena/Abrazadera_dipolo.SLDPRT
src/cad-design/Antena/Dipolo-2.SLDPRT
src/cad-design/Antena/Director-2.SLDPRT
src/cad-design/Macro/17HS4401.SLDPRT
src/cad-design/Macro/Acople Tripode.SLDPRT
src/cad-design/Macro/Acople antena.SLDPRT
src/cad-design/Macro/Brida antena.SLDPRT
src/cad-design/Macro/Brida engrane bot.SLDPRT
src/cad-design/Macro/Brida engrane top.SLDPRT
src/cad-design/Macro/Brida mid.SLDPRT
src/cad-design/Macro/Brida motores.SLDPRT
src/cad-design/Macro/Brida top.SLDPRT
src/cad-design/Macro/Caja electrónica.SLDPRT
src/cad-design/Macro/Caja motor.SLDPRT
src/cad-design/Macro/Contrapeso antena.SLDPRT
src/cad-design/Macro/Contrapeso estructura.SLDPRT
src/cad-design/Macro/Eje horizontal 8 mm.SLDPRT
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

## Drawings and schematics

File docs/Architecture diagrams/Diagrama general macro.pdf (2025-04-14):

## DIAGRAMA GENERAL

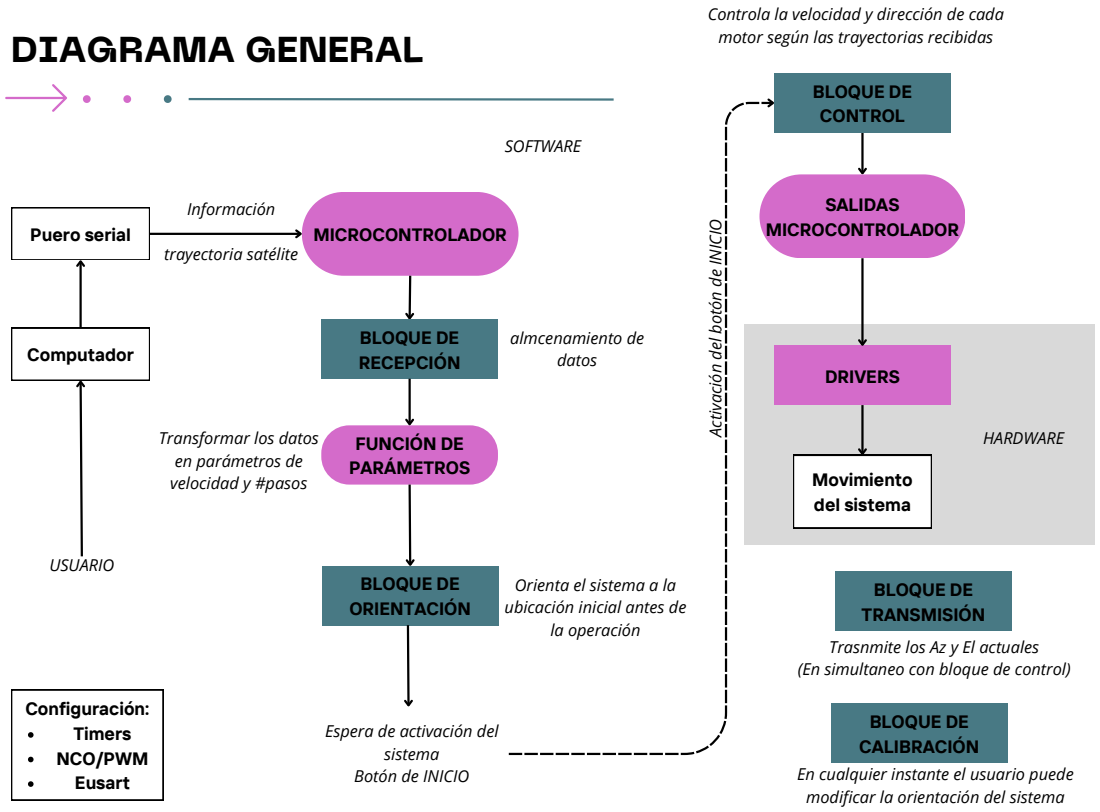
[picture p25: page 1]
MICROCONTROLADOR; BLOQUE DE RECEPCIÓN; Puero serial; FUNCIÓN DE PARÁMETROS; SALIDAS MICROCONTROLADOR; DRIVERS; Información; trayectoria satélite; almcenamiento de datos; ctiv; ció; otó; e INICIO; HARDWARE; SOFTWARE; BLOQUE DE ORIENTACIÓN; BLOQUE DE CONTROL; Movimiento del sistema; Computador; USUARIO; Configuración: Timers NCO/PWM Eusart

Controla la velocidad y dirección de cada
motor según las trayectorias recibidas

Transformar los datos
en parámetros de
velocidad y #pasos

Orienta el sistema a la
ubicación inicial antes de
la operación

BLOQUE DE
TRANSMISIÓN
Trasnmite los Az y El actuales
(En simultaneo con bloque de control)

Espera de activación del
sistema
Botón de INICIO

CALIBRACIÓN
En cualquier instante el usuario puede
modificar la orientación del sistema

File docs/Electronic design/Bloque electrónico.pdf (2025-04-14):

## BLOQUE ELECTRÓNICO

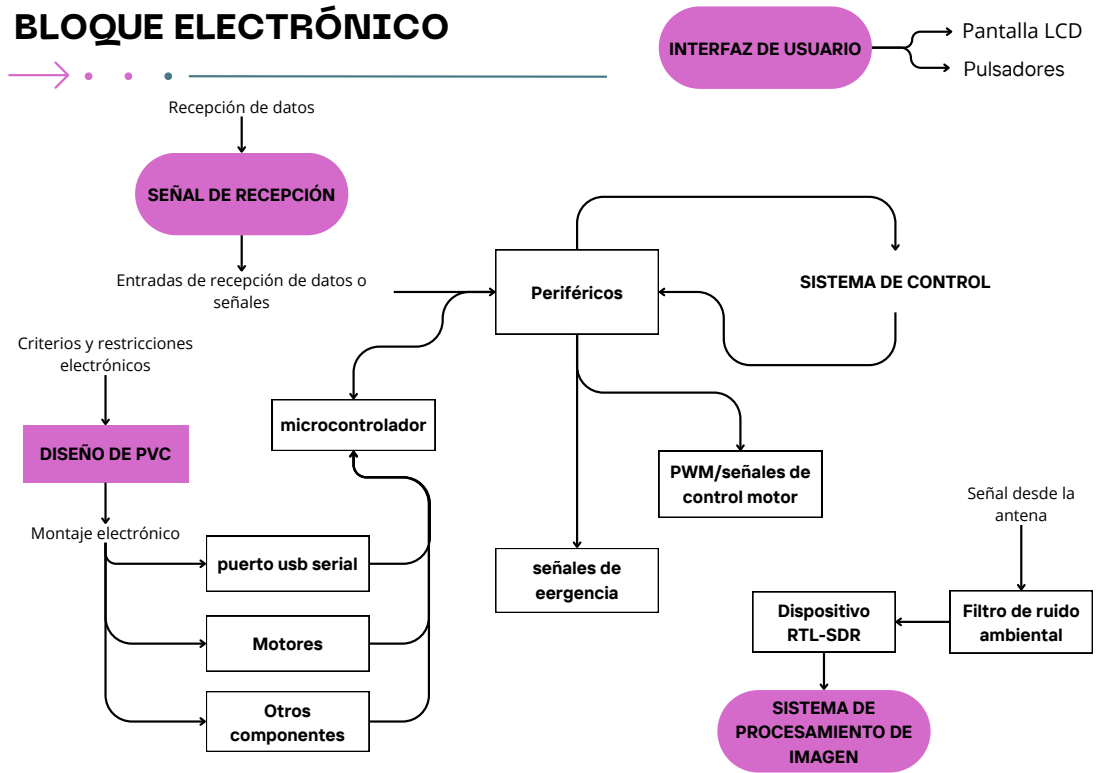
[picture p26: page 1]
Periféricos; Motores; Dispositivo RTL-SDR; señales; Montaje electrónico; microcontrolador; SISTEMA DE PROCESAMIENTO DE IMAGEN; Otros componentes; Criterios y restricciones electrónicos; señales de eergencia; Pantalla LCD; Pulsadores

INTERFAZ DE USUARIO

Recepción de datos

SEÑAL DE RECEPCIÓN

Entradas de recepción de datos o

SISTEMA DE CONTROL

DISEÑO DE PVC

PWM/señales de
control motor

Señal desde la
antena

puerto usb serial

Filtro de ruido
ambiental

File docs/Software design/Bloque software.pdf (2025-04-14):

## BLOQUE DE SOFTWARE

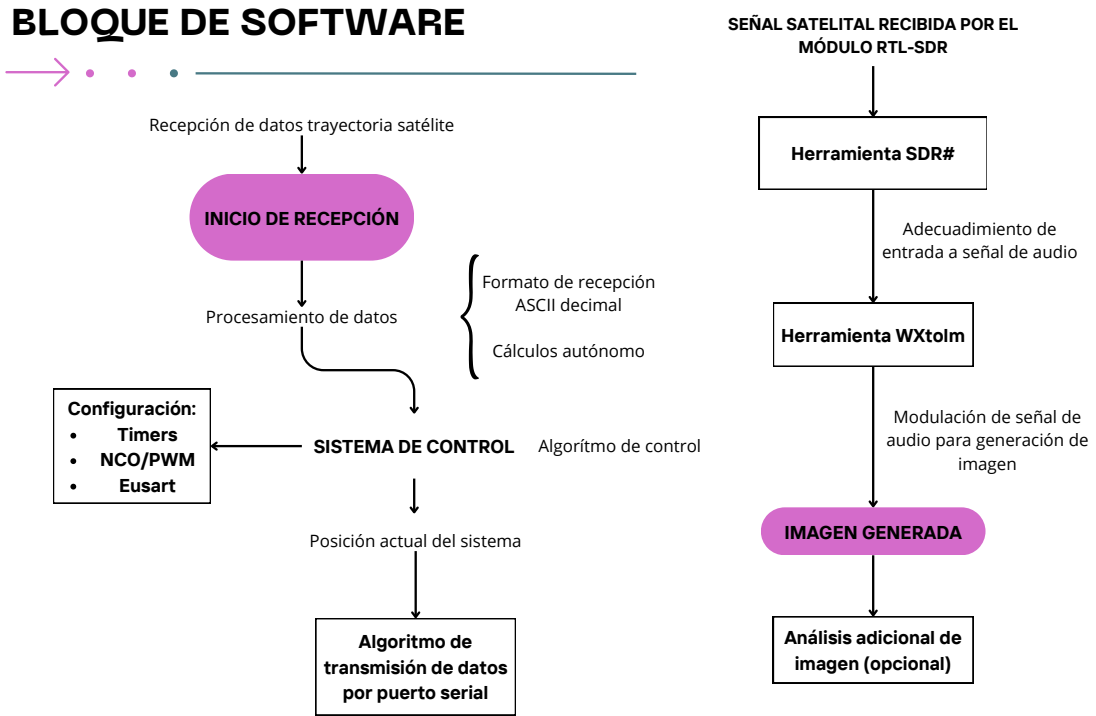
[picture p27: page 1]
Herramienta SDR#; Herramienta WXtolm; IMAGEN GENERADA; Configuración: Timers NCO/PWM Eusart; imagen; Cálculos autónomo

SEÑAL SATELITAL RECIBIDA POR EL

MÓDULO RTL-SDR

Recepción de datos trayectoria satélite

INICIO DE RECEPCIÓN

Adecuadimiento de
entrada a señal de audio

Formato de recepción
ASCII decimal

Procesamiento de datos

Modulación de señal de
audio para generación de

SISTEMA DE CONTROL

Algorítmo de control

Posición actual del sistema

Análisis adicional de
imagen (opcional)

Algoritmo de
transmisión de datos
por puerto serial

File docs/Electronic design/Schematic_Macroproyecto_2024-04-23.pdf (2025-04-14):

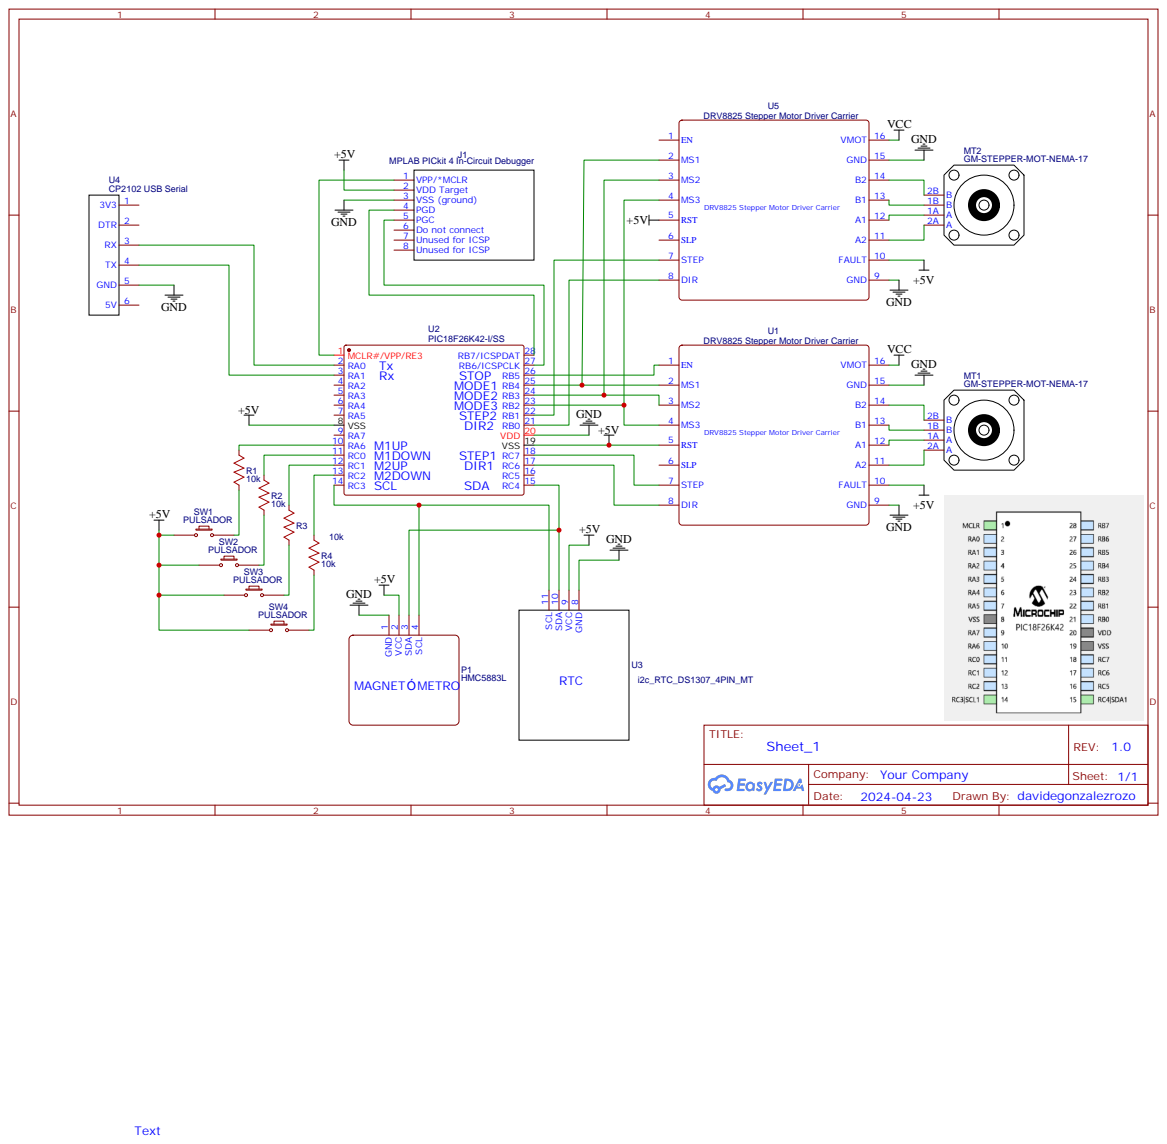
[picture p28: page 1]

DRV8825 Stepper Motor Driver Carrier

GM-STEPPER-MOT-NEMA-17

MPLAB PICkit 4 In-Circuit Debugger J1

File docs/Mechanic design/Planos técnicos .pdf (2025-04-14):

6,35 0.01

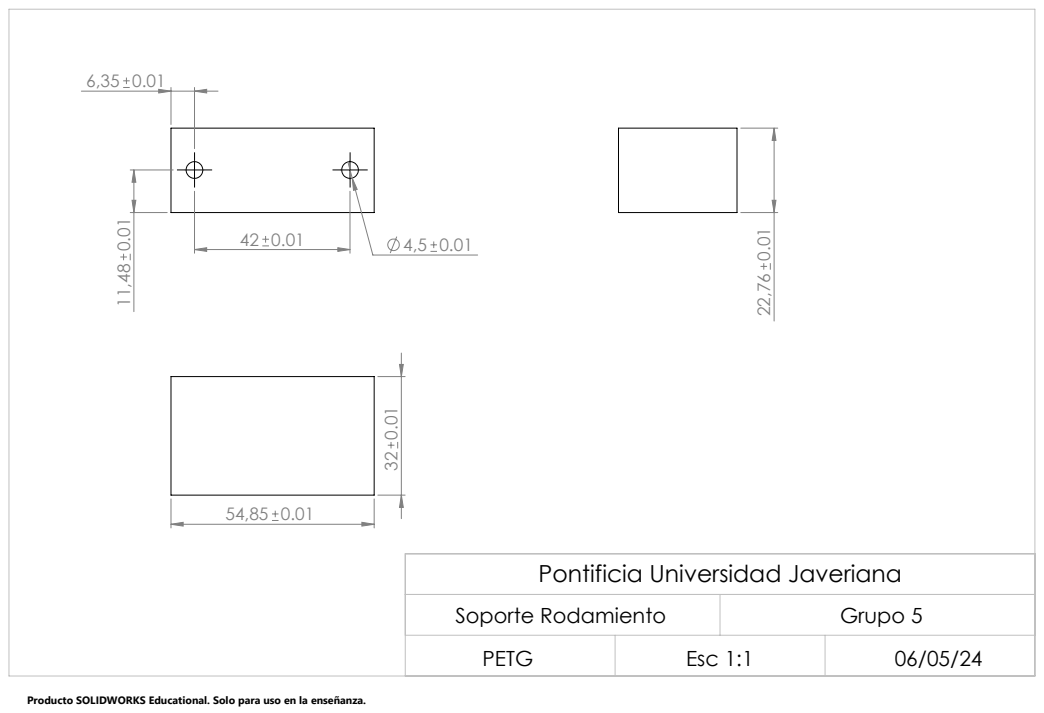
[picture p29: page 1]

Pontificia Universidad Javeriana

Soporte Rodamiento | Grupo 5
PETG | Esc 1:1 | 06/05/24

Producto SOLIDWORKS Educational. Solo para uso en la enseñanza.

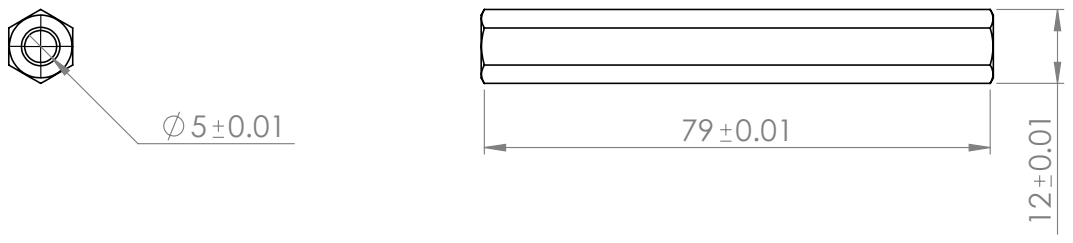
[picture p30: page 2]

Pontificia Universidad Javeriana

Standoff | Grupo 5
Aluminio | Esc 1:1 | 06/05/24

35 0.01

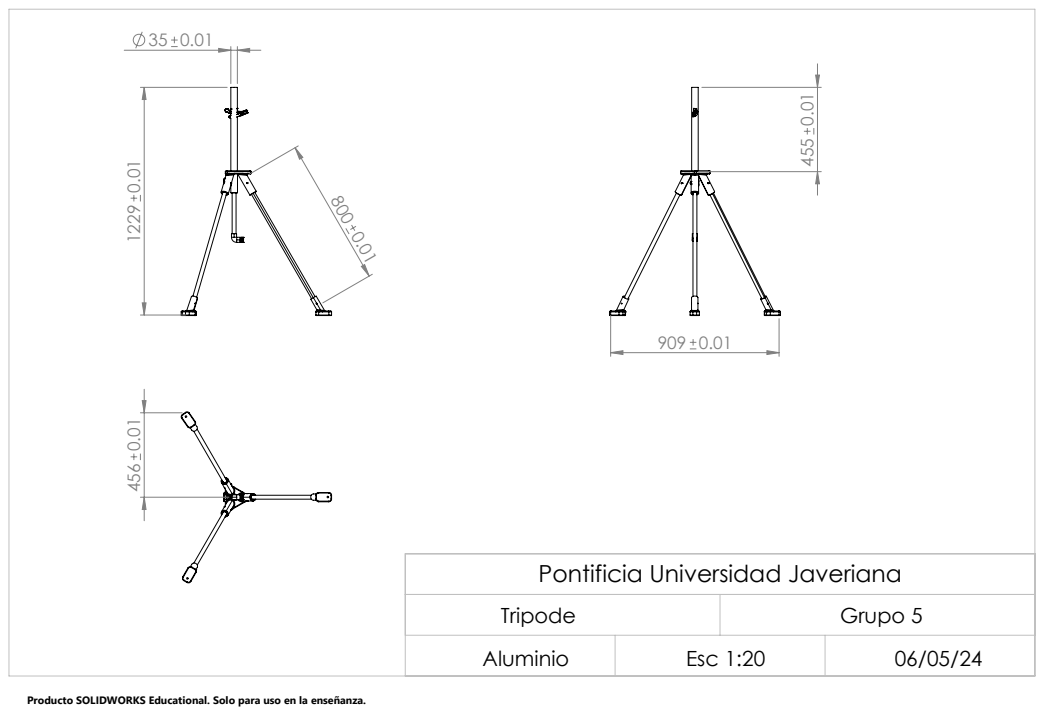
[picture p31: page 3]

Pontificia Universidad Javeriana

Tripode | Grupo 5
Aluminio | Esc 1:20 | 06/05/24

X 8 8 0.01

D

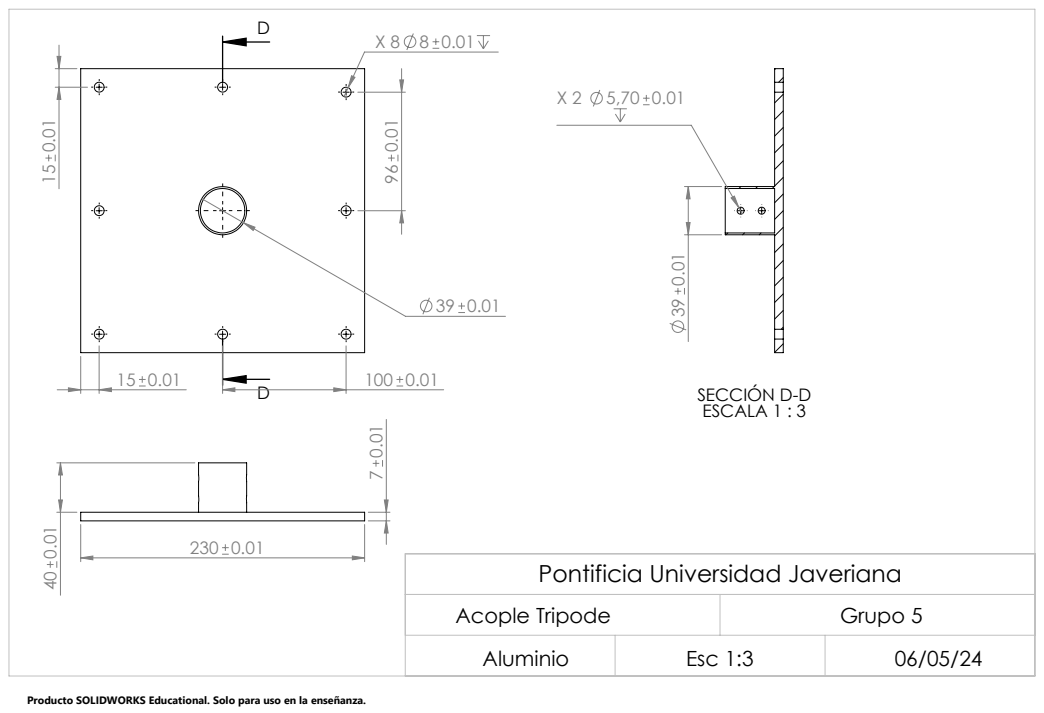
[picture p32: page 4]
SECCIÓN D-D ESCALA 1 : 3

Pontificia Universidad Javeriana

Acople Tripode | Grupo 5
Aluminio | Esc 1:3 | 06/05/24

14,7 | 0.01
3,00 | 0.01

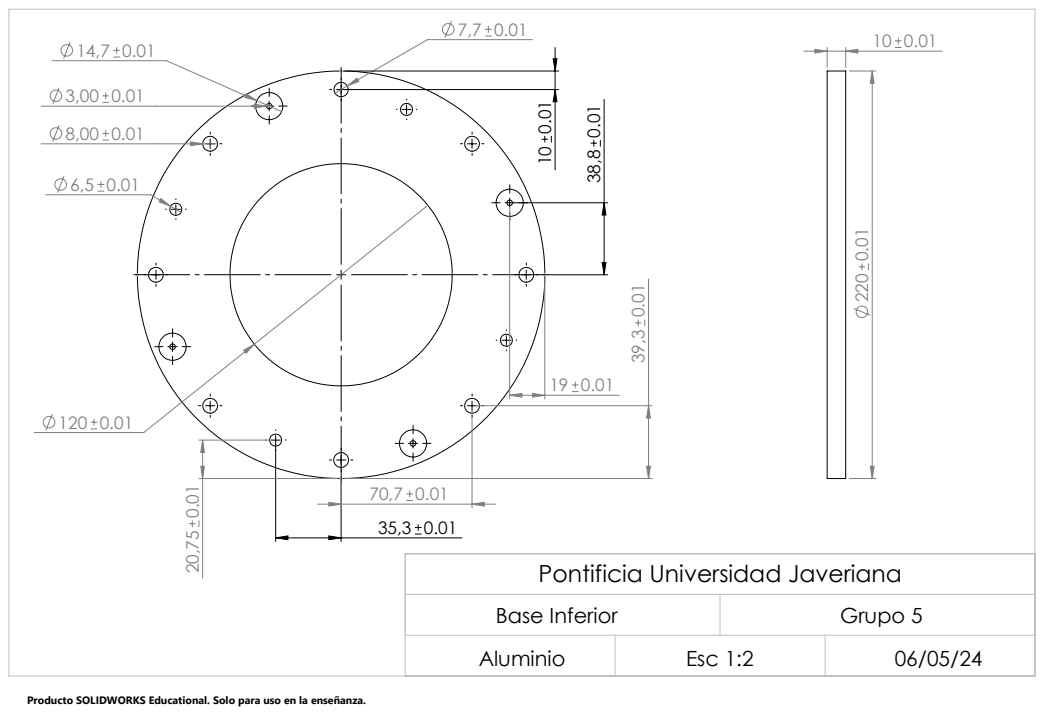
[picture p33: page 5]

Pontificia Universidad Javeriana

Base Inferior | Grupo 5
Aluminio | Esc 1:2 | 06/05/24

8 | 0.01
52 | 0.01

Pontificia Universidad Javeriana

Base Media | Grupo 5
Aluminio | Esc 1:2 | 06/05/24

12 | 0.01
X 4 5 | 0.01

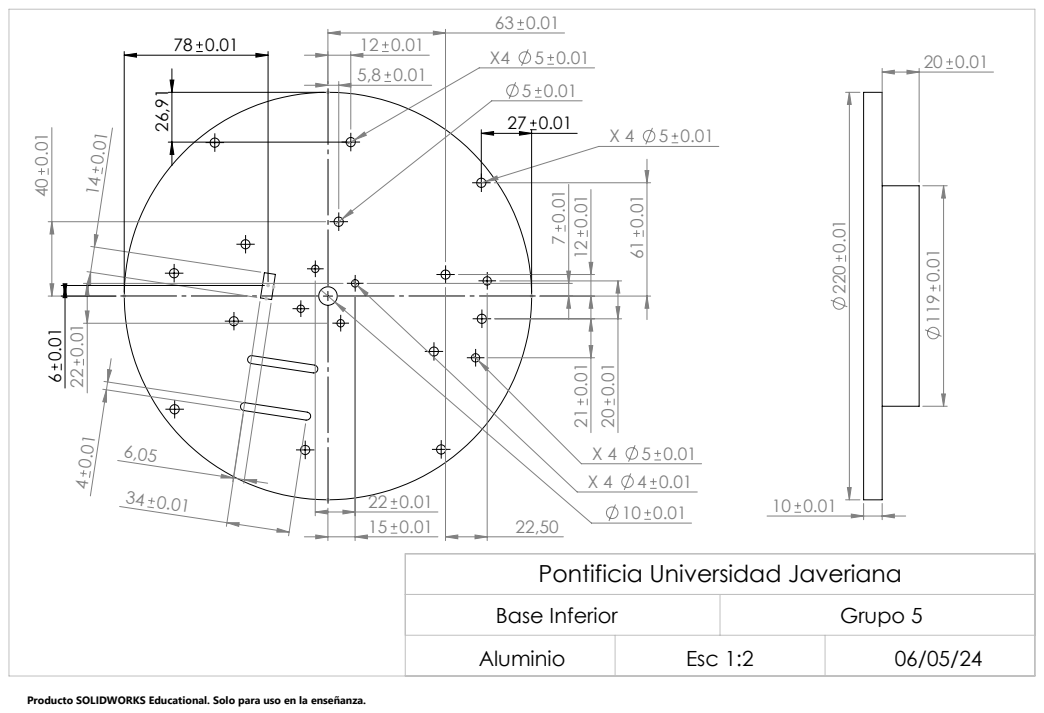
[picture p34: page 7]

Pontificia Universidad Javeriana

Base Inferior | Grupo 5
Aluminio | Esc 1:2 | 06/05/24

X 6 6 | 0.01
19,8 | 0.01

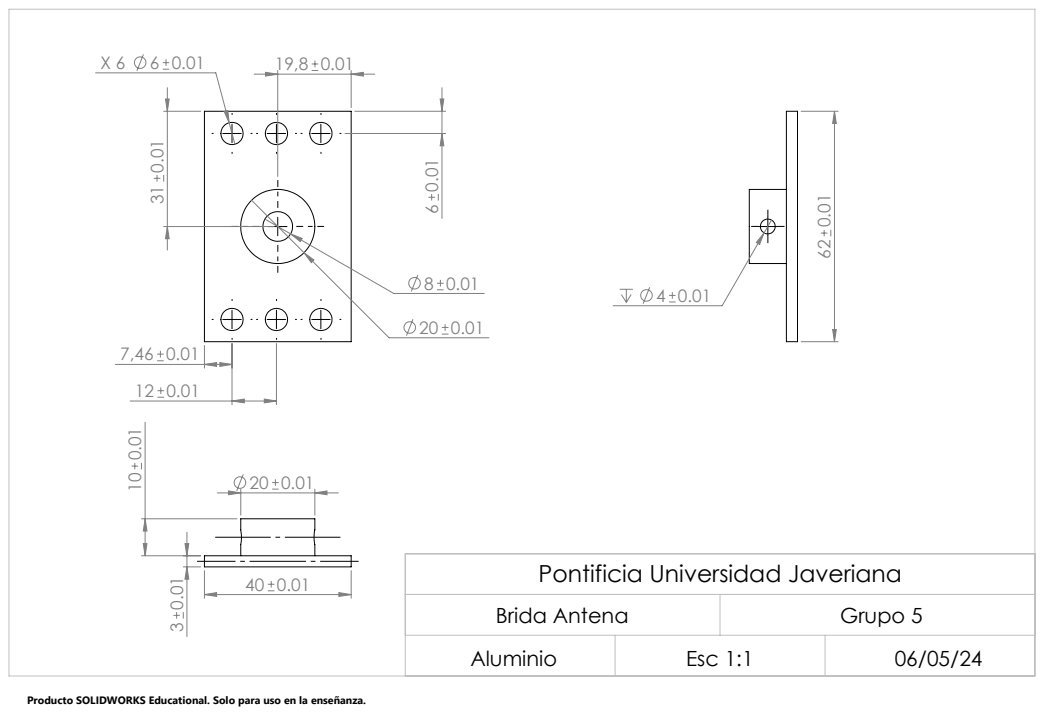
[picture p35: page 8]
Pontificia Universidad Javeriana

Brida Antena | Grupo 5
Aluminio | Esc 1:1 | 06/05/24

X 4 4

15,31 0.01

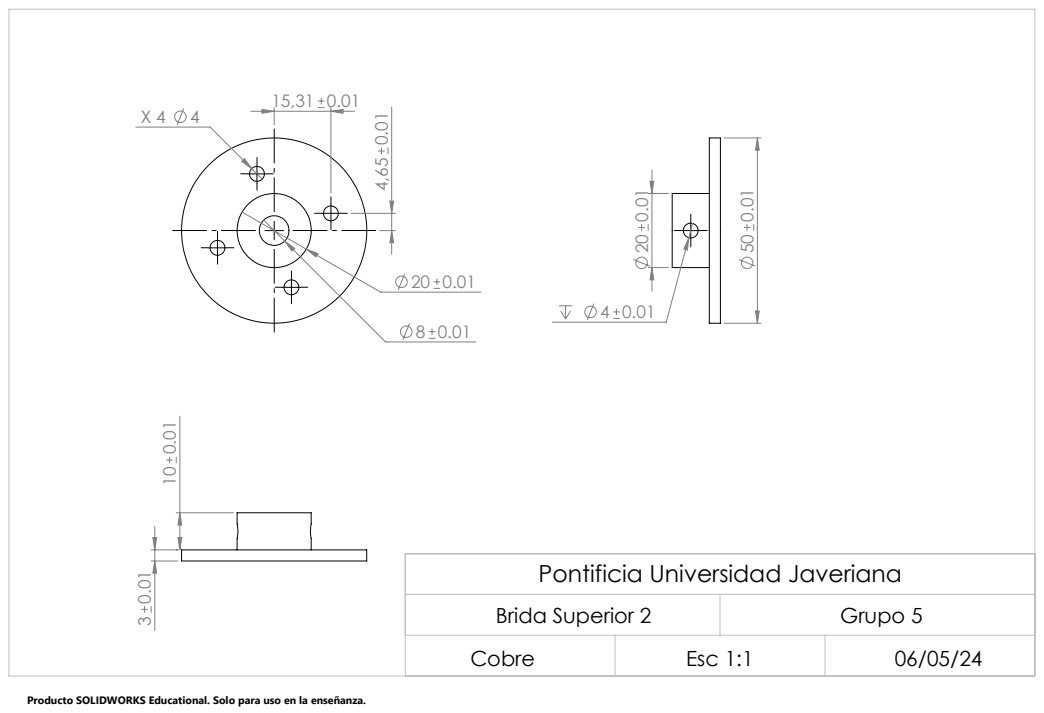
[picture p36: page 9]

Pontificia Universidad Javeriana

Brida Superior 2 | Grupo 5
Cobre | Esc 1:1 | 06/05/24

4,65 0.01


Pontificia Universidad Javeriana

Brida Superior | Grupo 5
Cobre | Esc 1:1 | 06/05/24

X4 | 4 | 0.01
7 | 0.01


Pontificia Universidad Javeriana

Brida Mitad | Grupo 5
Cobre | Esc 1:1 | 06/05/24

15,00 | 0.01
6 | 0.01


Pontificia Universidad Javeriana

Brida Motores | Grupo 5
Cobre | Esc 1:1 | 06/05/24

8 | 0.01
X4 4 | 0.01


Pontificia Universidad Javeriana

Brida Top | Grupo 5
Aluminio | Esc 1:1 | 06/05/24

3 0.01

A

SECCIÓN A-A

Pontificia Universidad Javeriana

Caja Electronica | Grupo 5
PETG | Esc 1:1 | 06/05/24

SECCIÓN B-B; Pontificia Universidad Javeriana; PETG; Esc 1:1; Caja Motor; Grupo 5

33,4 | 0.01 C
48,5 | 0.01

SECCIÓN C-C ESCALA 1 : 1

Pontificia Universidad Javeriana

Comtrapeso Antena | Grupo 5
Bronce | Esc 2:1 | 06/05/24

40 0.01


Pontificia Universidad Javeriana

Comtrapeso | Grupo 5
Bronce | Esc 2:1 | 06/05/24

Pontificia Universidad Javeriana; Acero; Esc 1:2; Eje 10 mm; Grupo 5

Pontificia Universidad Javeriana; Acero; Esc 1:2; Eje 8 mm 1; Grupo 5

10 0.01


Pontificia Universidad Javeriana

Rodamiento de brida ovalada | Grupo 5
Acero | Esc 2:1 | 06/05/24

Pontificia Universidad Javeriana

Rodamiento de bola | Grupo 5
Aluminio | Esc 4:1 | 06/05/24

120 | 0.01
5 | 0.01


Pontificia Universidad Javeriana

Rodamiento de Mesa | Grupo 5
Aluminio | Esc 1:2 | 06/05/24


Pontificia Universidad Javeriana

Rodamientos | Grupo 5
Acero | Esc 2:1 | 06/05/24

6 0.01


Pontificia Universidad Javeriana

Soporte Medio Antena | Grupo 5
PETG | Esc 2:1 | 06/05/24

5 0.01


Pontificia Universidad Javeriana

Engranaje 15T | Grupo 5
Acero | Esc 2:1 | 06/05/24

10 0.01


Pontificia Universidad Javeriana

Engranaje 30T | Grupo 5
Acero | Esc 1:2 | 06/05/24

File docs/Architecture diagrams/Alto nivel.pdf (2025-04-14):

Antena yagi; Imagen generada; Robot (2 DoF); Satélites NOAA; Órbita polar; Ángulos de coordenadas; RESULTADO; RTL-SDR

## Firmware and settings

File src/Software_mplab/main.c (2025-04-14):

/**
  Generated Main Source File

  Company:
    Microchip Technology Inc.

  File Name:
    main.c

  Summary:
    This is the main file generated using PIC10 / PIC12 / PIC16 / PIC18 MCUs

  Description:
    This header file provides implementations for driver APIs for all modules selected in the GUI.
    Generation Information :
        Product Revision  :  PIC10 / PIC12 / PIC16 / PIC18 MCUs - 1.81.8
        Device            :  PIC18F26K42
        Driver Version    :  2.00
*/

/*
    (c) 2018 Microchip Technology Inc. and its subsidiaries. 
    
    Subject to your compliance with these terms, you may use Microchip software and any 
    derivatives exclusively with Microchip products. It is your responsibility to comply with third party 
    license terms applicable to your use of third party software (including open source software) that 
    may accompany Microchip software.
    
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
    IN NO EVENT WILL MICROCHIP BE LIABLE FOR ANY INDIRECT, SPECIAL, PUNITIVE, 
    INCIDENTAL OR CONSEQUENTIAL LOSS, DAMAGE, COST OR EXPENSE OF ANY KIND 
    WHATSOEVER RELATED TO THE SOFTWARE, HOWEVER CAUSED, EVEN IF MICROCHIP 
    HAS BEEN ADVISED OF THE POSSIBILITY OR THE DAMAGES ARE FORESEEABLE. TO 
    THE FULLEST EXTENT ALLOWED BY LAW, MICROCHIP'S TOTAL LIABILITY ON ALL 
    CLAIMS IN ANY WAY RELATED TO THIS SOFTWARE WILL NOT EXCEED THE AMOUNT 
    OF FEES, IF ANY, THAT YOU HAVE PAID DIRECTLY TO MICROCHIP FOR THIS 
    SOFTWARE.
*/

#include "mcc_generated_files/mcc.h"
#include "math.h"

/*
                        Macros generales
*/
#define micro 16         // Resolución de micropasos stepper motor 
#define Angulo 1.8      // Giro en grados del motor por paso
#define pi 3.141592
#define w_max 0.07     //Velocidad máxima rad/s (modo manual)
//----------------------------------------------------------------

/*
                            FUNCTIONS
*/
void calibracion(void);
void recepcion(void);
void f_gps(void);
void parametros(void);
void orientacion(void);
void inicio(void);
void seguimiento(void);
void transmision(void);
void ang2msj(void);
void emergency(void);

//----------------------------------------------------------------

/*
                            Variables
*/

int8_t Rx_data[33];

uint8_t state;
bool direccion1, direccion2, bandera = 0;
uint16_t Azi, Azm, Azf, Steps_ini, Steps1[2], Steps2, pos_ini;
int El, hi, hm, hf, mi, mm, mf, Time[2];
float M1_Ang[2], M2_Ang, M1_Vel[2], M2_Vel, Frec_max;
uint32_t N1 = 0, Yr1 = 0, N2 = 0, Yr2 = 0;  
float Avance, ang2step,ang2rad, w2sps, aux;

uint8_t msj1[4], msj2[4], cont = 0, contador = 0; 
uint16_t ref = 0;

bool flag_timer_Tx = 0, flag_gps = 0, Apagar1 = 0, Apagar2 = 0;
uint16_t tope1 = 0, tope2 = 0;

int buffer[15], gps = 0;
int8_t hora_gps, min_gps;
float Az_gps;

/*
                         Main application
*/
void main(void)
{
    // initialize the device
    SYSTEM_Initialize();

    // Enable the Global Interrupts
    INTERRUPT_GlobalInterruptEnable();

    // INICIALIZACIÓN
    state = 0;
    Avance = Angulo/micro;
    ang2step = 1/Avance;  
    w2sps = 180/Avance/pi;
    aux = w2sps*4/36500;
    ang2rad = pi/180;
    ENABLE_SetLow();
    LED_VERDE_SetLow();
    LED_ROJO_SetLow();
    
    //N1 = 223*ang2step;
    //N2 = 82*ang2step;
    Frec_max = w_max*w2sps;
    tope1 = 1/(w_max*aux);
    tope2 = 1/(w_max*aux);
    
    MS0_SetHigh();
    MS1_SetHigh();
    MS2_SetHigh();
    
    //MULTIPLICAR X2 TANTO LA VELOCIDAD COMO LA CANTIDAD DE PASOS A DAR
    
    while (1)
    {  
        switch(state){
            case 0: 
                calibracion();
                recepcion();
                //f_gps();
                break;
            case 1: 
                parametros();
                break;
            case 2: 
                orientacion(); 
                break;
            case 3: 
                f_gps();
                inicio();
                break;
            case 4:
                seguimiento();
                break;
        }   /* End switch-case */
        
        emergency();                         
        if( flag_timer_Tx ){
            flag_timer_Tx = 0;
            transmision();
        }      
       
    }   /* End while */
}   /* End main */

/*
 *                  FUNCIÓN DE RECEPCIÓN DE DATOS
*/
void recepcion(){
    if( UART1_is_rx_ready() ){
        Rx_data[contador] = UART1_Read()-48;   
        
        if( Rx_data[contador] == -38 ){
            Azi = (Rx_data[0]*100) + (Rx_data[1]*10) + (Rx_data[2]);
            Azm = (Rx_data[4]*100) + (Rx_data[5]*10) + (Rx_data[6]);
            Azf = (Rx_data[8]*100) + (Rx_data[9]*10) + (Rx_data[10]);
            El  = (Rx_data[12]*10 + Rx_data[13]);
            hi  = (Rx_data[15]*10 + Rx_data[16]);
            mi  = (Rx_data[18]*10 + Rx_data[19]);
            hm  = (Rx_data[21]*10 + Rx_data[22]);
            mm  = (Rx_data[24]*10 + Rx_data[25]);
            hf  = (Rx_data[27]*10 + Rx_data[28]);
            mf  = (Rx_data[30]*10 + Rx_data[31]);
            contador = 0;
            state = 1;
        }else contador+=1;
    }
    return;
}

/*
 *                  FUNCIÓN DE TRANSMISIÓN DE DATOS
*/
void transmision(){ 
    // TRANSFORMANDO PASOS A ÁNGULO
    ang2msj();          
    // ENVIANDOI ÁNGULO AZ
    UART1_Write(msj1[0]+48);    
    UART1_Write(msj1[1]+48);
    UART1_Write(msj1[2]+48);
    UART1_Write(msj1[3]+48);
    UART1_Write(10);            //(ganancia de 0.01))
    // ENVIANDO ÁNGULO EL
    UART1_Write(msj2[0]+48);    
    UART1_Write(msj2[1]+48);
    UART1_Write(msj2[2]+48);
    UART1_Write(msj2[3]+48);
    UART1_Write(44);  // ','         (ganancia de 0.01))         
    return;
}

// TRANSFORMACIÓN DE VEL ACTUAL 
void ang2msj(){
    ref = N1*Avance*10;                // ÁNGULO AZIMUTH
    msj1[3] = ref % 10;
    msj1[2] = ref / 10 % 10;
    msj1[1] = ref / 100 % 10;
    msj1[0] = ref / 1000 % 10;
    ref = N2*Avance*100;                // ÁNGULO ELEVATION
    msj2[3] = ref % 10;
    msj2[2] = ref / 10 % 10;
    msj2[1] = ref / 100 % 10;
    msj2[0] = ref / 1000 % 10;   
    return;
}

/*
 *                  FUNCIÓN DE CALIBRACIÓN MANUAL
*/
void calibracion(){
    
    if( AZ_R_GetValue() ){  // MOTOR AZ A LA DERECHA
        DIR1_SetLow();
        LED_VERDE_SetHigh();
        direccion1 = 0;
        Apagar1 = 1;
    }else if( AZ_L_GetValue() ){  // MOTOR AZ A LA IZQUIERDA
        DIR1_SetHigh();
        LED_VERDE_SetHigh();
        direccion1 = 1;
        Apagar1 = 1;
    }else{
        Apagar1 = 0;
        LED_VERDE_SetLow();
    }
    
    if( EL_R_GetValue() ){    // MOTOR EL A LA DERECHA
        DIR2_SetLow();
        LED_VERDE_SetHigh();
        direccion2 = 0;
        Apagar2 = 1;
    }else if( EL_L_GetValue() ){  // MOTOR EL A LA IZQUIERDA
        DIR2_SetHigh();
        LED_VERDE_SetHigh();
        direccion2 = 1;
        Apagar2 = 1;
    }else{
        Apagar2 = 0;
        LED_VERDE_SetLow();
    }
    return;
}

/*
 *                  FUNCIÓN DE USO DE GPS
*/
void f_gps(){
    if( flag_gps ){
        if( UART2_is_rx_ready() ){
            buffer[gps] = UART2_Read()-48;
            if( gps >= 15 ){
                hora_gps = buffer[9]*10 + buffer[10] - 5;
                if( hora_gps < 0 ) hora_gps = 24 - hora_gps;
                min_gps = buffer[11]*10 + buffer[12];
                //Az_gps = buffer[45]*100 + buffer[46]*10 + buffer[47] + buffer[49]*0.1;
                gps = 0;
                flag_gps = 0;
            }else gps += 1;
        }           
    }
    
    return;
}

void parametros(){
    
    //PARÁMETROS TRAMO 1
    Time[0] = ((hm-hi)*60) + ((mm-mi));
    M1_Ang[0] = abs(Azm-Azi);          // Motor Azimuth
    M1_Vel[0] = M1_Ang[0]*ang2rad/(Time[0]*60);      
    Steps1[0] = M1_Ang[0]*ang2step*2;    

    //PARÁMETROS TRAMO 2
    Time[1] = ((hf-hm)*60) + ((mf-mm));
    M1_Ang[1] = abs(Azf-Azm);          // Motor Azimuth
    M1_Vel[1] = M1_Ang[1]*ang2rad/(Time[1]*60);    
    Steps1[1] = M1_Ang[1]*ang2step*2; 
    
    M2_Ang = El;                        // Motor Elevation
    M2_Vel = M2_Ang*ang2rad/(((Time[0]+Time[1]))*30);     // En la mitad exacta de tiempo 
    Steps2 = M2_Ang*ang2step*2;   
    
    //-------------PARÁMETROS DE LA ORIENTACIÓN INICIAL--------------//
    //DIRECCIÓN DE ORIENTACIÓN
    if( Azi > 180 ){
        direccion1 = 1;
        pos_ini = 360 - Azi;
    }else{
        direccion1 = 0; 
        pos_ini = Azi;
    }
    Steps_ini = pos_ini*ang2step*2;
    
    // INICIALIZAR LA ORIENTACIÓN
    if( !direccion1 ){
        N1 = 0;
        DIR1_SetLow();
    }else{
        N1 = 360*ang2step;
        DIR1_SetHigh();
    }
    N2 = 0;
    Yr1 = 0;
    Apagar1 = 1;
    LED_VERDE_SetHigh();
    
    state = 2;
    return;
}

/*
 *                  FUNCIÓN DE ORIENTACIÓN INICIAL DEL SISTEMA
*/
void orientacion(){
    if( Yr1 >= Steps_ini){        
        //APAGAR LA ORIENTACIÓN
        LED_VERDE_SetLow();
        STEP1_SetLow();        
        Apagar1 = 0;
        
        //DIRECCIONES
        if( Azi < 180 ){
            if( Azi+180 > Azf && Azf > Azi ) direccion1 = 0;
            else direccion1 = 1;    
        }else{
            if( Azi-180 < Azf && Azi > Azf ) direccion1 = 1;
            else direccion1 = 0;    
        }
        direccion2 = 0;   
        
        state = 3;       
    }  
    return;
}

/*
 *                  FUNCIÓN DE INICIO DE SEGUIMIENTO
*/
void inicio(){
    if( AZ_R_GetValue() ){
    //if( hi == hora_gps && mi == min_gps ){
             
        if( !direccion1 ) DIR1_SetLow();
        else DIR1_SetHigh();           
        DIR2_SetLow();
        
        STEP1_SetHigh();
        STEP2_SetHigh();
            
        LED_VERDE_SetHigh();
        
        tope2 = 1/(M2_Vel*aux);   // *1000*2    a ms y luego a la mitad
        Yr1 = 0;
        Yr2 = 0;
        Apagar1 = 1;
        Apagar2 = 1;      
        state = 4; 
    }
    return;
}

/*
 *                  FUNCIÓN DE SEGUIMIENTO
*/
void seguimiento(){
    if( Yr1 <= Steps1[0] ){     // Az alcanza todo el recorrido  
        tope1 = 1/(M1_Vel[0]*aux);    // *1000*2    a ms y luego a la mitad
    }else{
        tope1 = 1/(M1_Vel[1]*aux);    // *1000*2    a ms y luego a la mitad
    }    
    
    if( Yr1 >= Steps1[0]+Steps1[1] ){     // Az alcanza todo el recorrido
        //APAGAR SEÑAL PASO DE MOTOR AZ
        STEP1_SetLow();
        DIR1_SetLow();
        Apagar1 = 0;
        Yr1 = 0;        
    }
    if( Yr2 >= Steps2 && Yr2 < Steps2*2 ){     // EL alcanza mitad del recorrido
        // INVERTIR DIRECCIÓN DE MOTOR EL
        direccion2 = 1;
        DIR2_SetHigh();
    }
    else if( Yr2 >= Steps2*2 ){   // EL alcanza todo el recorrido
        // APAGAR SEÑAL PASO MOTOR EL
        STEP2_SetLow();
        DIR2_SetLow();
        Apagar2 = 0;
        Yr2 = 0;
    }
    
    if( !Apagar1 && !Apagar2 ){ //-----------------------------
        bandera = 0;
        LED_VERDE_SetLow();
        state = 0;
    }
    return;
}

/*
 *                  FUNCIÓN DE PARADA DE EMERGENCIA
*/
void emergency(){  
    if ( EMERGENCY_GetValue() ){
        ENABLE_SetHigh(); 
        LED_ROJO_SetHigh();
    }
    return;
}

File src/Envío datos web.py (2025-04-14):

import requests
import json
import datetime
import serial

# Configura el puerto serial (ajusta 'COM3' y baudrate según tu configuración)
ser = serial.Serial('COM11', 9600)

# URL de la API
url = "https://api.n2yo.com/rest/v1/satellite/visualpasses/25338/41.702/-76.014/0/2/300/&apiKey=TV43BH-4XXWCB-H2M26M-58DX"
response = requests.get(url)

if response.status_code == 200:
    data = response.json()

    # Asumimos que la estructura de datos tiene los siguientes campos
    # Puedes ajustar esto según la estructura real de la respuesta de la API
    info = data.get('info', {})
    passes = data.get('passes', [])

    # Extraer información específica y almacenarla en variables
    sat_name = info.get('satname', '')
    transaction_count = info.get('transactionscount', 0)
    satellite_id = info.get('satid', 0)

    if passes:
        # Procesar solo el primer pase
        pass_info = passes[0]
        startAz = int(pass_info.get('startAz', 0)) 
        midAz = int(pass_info.get('maxAz', 0))
        endAz = int(pass_info.get('endAz', 0))
        maxEl = int(pass_info.get('maxEl', 0))
        tiempo_in = int(pass_info.get('startUTC', 0))
        tiempo_mi = int(pass_info.get('maxUTC', 0))
        tiempo_fi = int(pass_info.get('endUTC', 0))

        tiempo1 = datetime.datetime.fromtimestamp(tiempo_in)
        tiempo2 = datetime.datetime.fromtimestamp(tiempo_mi)
        tiempo3 = datetime.datetime.fromtimestamp(tiempo_fi)

        hora1 = tiempo1.hour
        minutos1 = tiempo1.minute

        hora2 = tiempo2.hour
        minutos2 = tiempo2.minute

        hora3 = tiempo3.hour
        minutos3 = tiempo3.minute

        # Imprimir la información del primer pase
        print(f"Pase 1:")
        print(f"  Azimuth Inicial: {startAz}")
        print(f"  Azimuth Medio: {midAz}")
        print(f"  Azimuth Final: {endAz}")
        print(f"  Elevación Medio: {maxEl}")
        print(f"  Hora Inicial: {hora1}")
        print(f"  Minutos Inicial: {minutos1}")
        print(f"  Hora Media: {hora2}")
        print(f"  Minutos Media: {minutos2}")
        print(f"  Hora Final: {hora3}")
        print(f"  Minutos Final: {minutos3} \n")

        # Convertir el Azimuth Inicial a string y enviar cada dígito como ASCII por el puerto serial
        for digit in str(startAz):
           ser.write(digit.encode('ascii'))

        ser.write(b',')

        for digit in str(midAz):
           ser.write(digit.encode('ascii'))

        ser.write(b',')

        for digit in str(endAz):
           ser.write(digit.encode('ascii'))

        ser.write(b',')

        for digit in str(maxEl):
           ser.write(digit.encode('ascii'))

        ser.write(b',')

        for digit in str(hora1):
           ser.write(digit.encode('ascii'))

        ser.write(b',')

        for digit in str(minutos1):
           ser.write(digit.encode('ascii'))

        for digit in str(hora2):
           ser.write(digit.encode('ascii'))

        ser.write(b',')

        for digit in str(minutos2):
           ser.write(digit.encode('ascii'))

        ser.write(b',')

        for digit in str(hora3):
           ser.write(digit.encode('ascii'))

        ser.write(b',')

        for digit in str(minutos3):
           ser.write(digit.encode('ascii'))


    # Imprimir la información del satélite
    print(f"Nombre del Satélite: {sat_name}")
    print(f"ID del Satélite: {satellite_id}")
    print(f"Conteo de Transacciones: {transaction_count}")

else:
    print("Error al obtener los datos:", response.status_code)

# Cerrar el puerto serial
ser.close()
